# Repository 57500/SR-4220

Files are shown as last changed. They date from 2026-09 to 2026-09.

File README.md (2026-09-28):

# SR-4220 针齿全轴承低成本RV减速器

57feaf2c608dee79a52db78fb02cc7f5

*(SR-4220 及各版本迭代全家福)*

## 📖 项目简介

**SR-4220** 是一款适配 **42步进电机** 的 **56速比** 低成本针齿全轴承 RV 减速器。本项目的初衷是为了学习和验证 RV 减速器的机械结构与运动学原理。

*   **适配电机**：42步进电机
*   **减速比**：56:1
*   **设计特点**：低成本、针齿全轴承设计

---

## ⚠️ 提醒

联系方式QQ：3480087763

其实我真的不建议复刻这个版本 T.T。
后面会有更好的设计。**除非你对 RV 实在是感兴趣，不然我建议只用来学习即可**。

因为是低价加工，精度不可能特别高，而众所周知 RV 减速器对精度要求特别高，所以这将会是一场**装配灾难**：三曲轴相对同心度、垂直度……唉唉，可惜我这优雅的设计竟败倒在了加工和装配误差面前。

不过用心点当然是可以装成功的！！毕竟我已经做了好几个了，只失败过一次（因为装齿轮的时候没对好齿）。如果你决定要复刻，请务必仔细阅读下方的复刻建议。

---

## 📷 实物与仿真展示

### 1. 成品照片
76c14007c5b237c34e0ec1a0f416fc58

### 2. 摆线盘静力学仿真
82e7bc1e6b90b81701126e20f0d91eb4
*（摆线盘单盘20牛米静力学仿真，von Mises应力分布图）*

---

## 🛠️ 复刻建议与避坑指南

### 一、 加工与采购指南
1. **铝CNC件**：可以直接另存为STEP，然后上传 **铨洲智能制造** 加工。摆线盘和偏心套选择**精加工**，其他不选精加工。
2. **轴承采购**：轴承量很大，可以直接上 **1688** 找那种专门做轴承的。693ZZ这样的轴承钢轴承只要五毛钱一个，如果选碳钢好像只要一毛钱一个。
3. **齿轮标准件**：都是可以直接上淘宝买到的，一般五六块钱一个。中间太阳轮齿轮选 **K型**，行星轮选 **A型**，行星轮可以备注一下要 **松配合** 的。
4. **分体曲轴D型轴**：这个D型轴其实有点贵，好像要四块钱一根。
5. **PLA垫片**：设计里涉及到的PLA垫片，可以直接换成相应内径的 **金属垫片**（偷懒没有在图里面改了）。
6. **手工铰刀**：可以买个 **D3的手工铰刀** 备用，防止加工误差导致销轴插不进去。

### 二、 装配与点胶注意事项
7. **点胶规范**：看装配过程中，要点轴承胶的记得点胶，用 **乐泰638** 就行。**记得千万不能弄多了，不然渗入轴承就不好搞了！** 还有一定要小心点，因为沾上了之后就很难拆下来了。
8. **点胶位置**：主要是 **分体曲轴部分** 还有 **曲轴和摆线盘配合处**，相当于轴向约束。
9. **针齿轴承装配**：针齿轴承部分有可能因为轴承公差问题很难穿进去，所以很建议你有个 **压台** 方便装配。
10. **垂直度控制**：摆盘和曲轴点胶的时候千万要小心，**要保证垂直度**，不然会上下偏振的。
11. **太阳轮顶丝**：拧的时候记得小心些，不然有可能滑丝就拆不下来了。

### 三、 调试与磨合
12. **反驱测试**：带电机装配好后试试可不可以反驱。如果根本反驱不了说明装配有问题（垂直度会影响齿轮啮合），不过不用太担心，**先不要加润滑脂**，直接上电 **干磨**，运行个一个小时，直到磨合到能够反驱即可。
13. **反驱力说明**：带电机反驱力很大是正常的，毕竟这可是42步进电机齿槽转矩放大了56倍之后的反驱力。

### 四、 外观与结构优化
14. **结构简化**：如果不想要双端固定的话，可以把底下的结构去掉，直接用打印件外壳就行了。
15. **外观处理**：想要外观好看些可以把铝件外壳选择 **阳极氧化黑色**（不过要多花几十块钱），当然也可以直接金属喷漆，不过我没这么试过。

---

## 📖 预告
62e3c3735a7298865c6b1d279f5857ca

自研机械臂正在制作中......

## 🤝 结语
暂时只想到这些了。希望这份指南能帮到想要学习 RV 减速器的朋友，祝大家装配顺利！

*如果觉得有帮助，欢迎点个 Star ⭐*

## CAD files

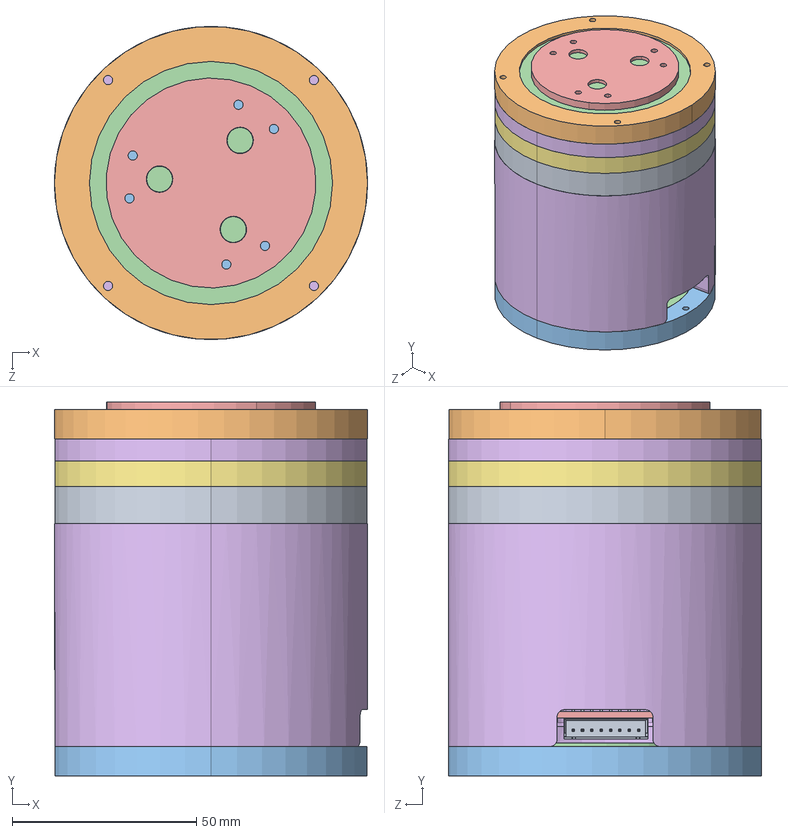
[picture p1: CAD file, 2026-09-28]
SR-4220-L48-R56.STEP
85.0 x 101.5 x 85.0 mm
铝CNC-6709外圈轴承套-SR-4220
铝CNC-6711外圈轴承套-SR-4220
铝CNC-摆线盘-SR-4220 x 2
铝CNC-夹紧圆盘-SR-4220
铝CNC-输出法兰-SR-4220
铝CNC-针齿上层固定环-SR-4220
铝CNC-针齿下层固定环-SR-4220
PLA-3.2X4.2X0.5垫片-SR-4220 x 44
PLA-5.2X6.2X0.5垫片-SR-4220 x 3
PLA-太阳轮定位套-SR-4220
成品-6709ZZ轴承-SR-4220
成品-6711ZZ轴承-SR-4220 x 2
成品-693ZZ轴承-SR-4220 x 44
成品-MF85法兰轴承-SR-4220 x 6
成品-MR105ZZ轴承-SR-4220
成品-MR148ZZ轴承-SR-4220 x 6
成品-0.5模16齿5孔黄铜齿轮-凸台-SR-4220_CCLC-C2W-C~CCLC-S1W-C-K
成品-0.5模40齿5孔黄铜齿轮-SR-4220_CCLC-C2W-C~CCLC-S1W-C-A x 3
成品-3X12圆柱销-SR-4220 x 22
成品-4XM3X18塞打螺栓-SR-4220 x 3
成品-ZDT_X42_L48Motor-SR-4220
PCB-转接板-SR-4220
成品-M3D5L60铝柱-SR-4220 x 4
hexagon socket head cap screws gb_GB_FASTENER_SCREWS_HSHCS M3X6-N
铝CNC-6712外圈轴承套-SR-4220
铝CNC-6712内圈轴承套-SR-4220
铝CNC-尾部输出法兰-SR-4220
PLA-电机保护壳-SR-4220
成品件-5X20D型圆柱销-SR-4220 x 3
铝CNC-偏心套上-SR-4220 x 3
铝CNC-偏心套下-SR-4220 x 3
PLA-3.2X4.2X1垫片-SR-4220 x 22
